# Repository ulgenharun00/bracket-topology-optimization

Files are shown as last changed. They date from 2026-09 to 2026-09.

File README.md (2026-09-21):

# Structural Optimization & Lightweighting of an Industrial Robot Arm Bracket




This repository contains the CAD models, FEA simulation results for a topology optimized robot arm bracket under a **500 N peak dynamic load**.

## 📌 Project Overview
* **Objective:** Reduce inertia and mass at the robot flange while strictly preserving structural rigidity and conventional machinability (DFM).
* **Baseline Material:** Structural Steel S235JR
* **Substituted Material:** EN AW-6061-T6 Aluminum Alloy

## 📊 Key Results & Comparison
| Metric / Parameter | Baseline Steel Bracket | Optimized Aluminum Bracket | Change |
| :--- | :---: | :---: | :---: |
| **Mass** | 742.16 g | **199.06 g** | **-73.18%** |
| **Peak von Mises Stress** | 20.67 MPa | 22.64 MPa | Well within yield limit |
| **Static Safety Factor** | 11.37 | **10.60** | Safe |
| **Max Total Deflection** | 0.027 mm | **0.071 mm** | Within L/1000 (0.080 mm) |
| **Fatigue Safety Factor**| 7.02 | **2.65** | Infinite Life (> 10^9 cycles) |

## 🛠️ Software & Standards Used
* **CAD:** SolidWorks (Part Modeling, Technical Drawings)
* **FEA:** ANSYS Mechanical (Adaptive Mesh Convergence, Fatigue Analysis, Topology Optimization)
* **Engineering Standards:** DIN EN 10056-1, ISO 898-1 (Class 8.8 Fasteners), DIN EN ISO 7090, Tabellenbuch Metall

## 📁 Repository Contents
* `/Report`: Complete 26 page engineering report.
* `/CAD`: SolidWorks (.SLDPRT) and neutral (.STEP) exchange models for both designs.
* `/Drawings`: Manufacturing drawings.
* `/Media` : High resolution stress plots and optimization density maps.

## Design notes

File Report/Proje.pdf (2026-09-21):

## Structural Optimization and Economic Feasibility of an Industrial Robot Arm Bracket

### 1. Design Load & Operating Scenario

The L-bracket serves as the structural interface between the robot flange and the end effector. To establish the design boundary conditions, a worst case scenario is assumed that 4g peak dynamic acceleration is induced as the on a robot arm handling a hypothetical 10 kg payload capacity:

F = m ⋅ (g + amax) = 10 kg × (9.81 + 40) m/s² ≈ 500 N

### 2. Bending Moment at the Root Section

The horizontal leg is evaluated as a cantilever beam with an effective overhang length of L = 80 mm. The peak bending moment acting on the fixed root section is:

Mb = F ⋅ L = 500 N ⋅ 80 mm = 40 000 N ⋅ mm

### 3. Allowable Stress & Safety Requirement

Baseline Design A utilizes standard structural steel S235JR (Re = 235 MPa). To ensure durability and prevent early plastic deformation under dynamic cyclic loading, an engineering safety factor of ν = 2.0 is defined:

σbzul =

σbF
v

=

235 MPa
2.0

= 117.5 MPa

### 4. Minimum Wall Thickness Calculation

Considering the bracket width as B = 80 mm, the required section modulus (Werf) to sustain the bending load is:

Werf =

Mb

σbzul

=

40 000 N ⋅ mm
117.5 N/mm² ≈ 340.4 mm³

Modeling the root section as a rectangular profile (W =

B⋅t

2

6

), the theoretical minimum wall thickness (terf) is derived as:

W =

B ⋅ t

2
6

⟹ terf = √
6 ⋅ Werf
B

= √
6 ⋅ 340.4 mm³
80 mm

≈ 5.05 mm

### 5. Standard Profile Selection

To maintain a safe structural margin, resist dynamic fatigue, and compensate for stress concentrations around the mounting holes, standard profile L 80 × 80 × 8 (DIN EN 10056-1)
[2] is selected. The nominal thickness of t = 8 mm safely exceeds the analytical minimum requirement of 5.05 mm.

Note: While σbF ≈ 1.2 ⋅ Re per Tabellenbuch Metall [1], using unmodified Re provides a conservative safety margin.

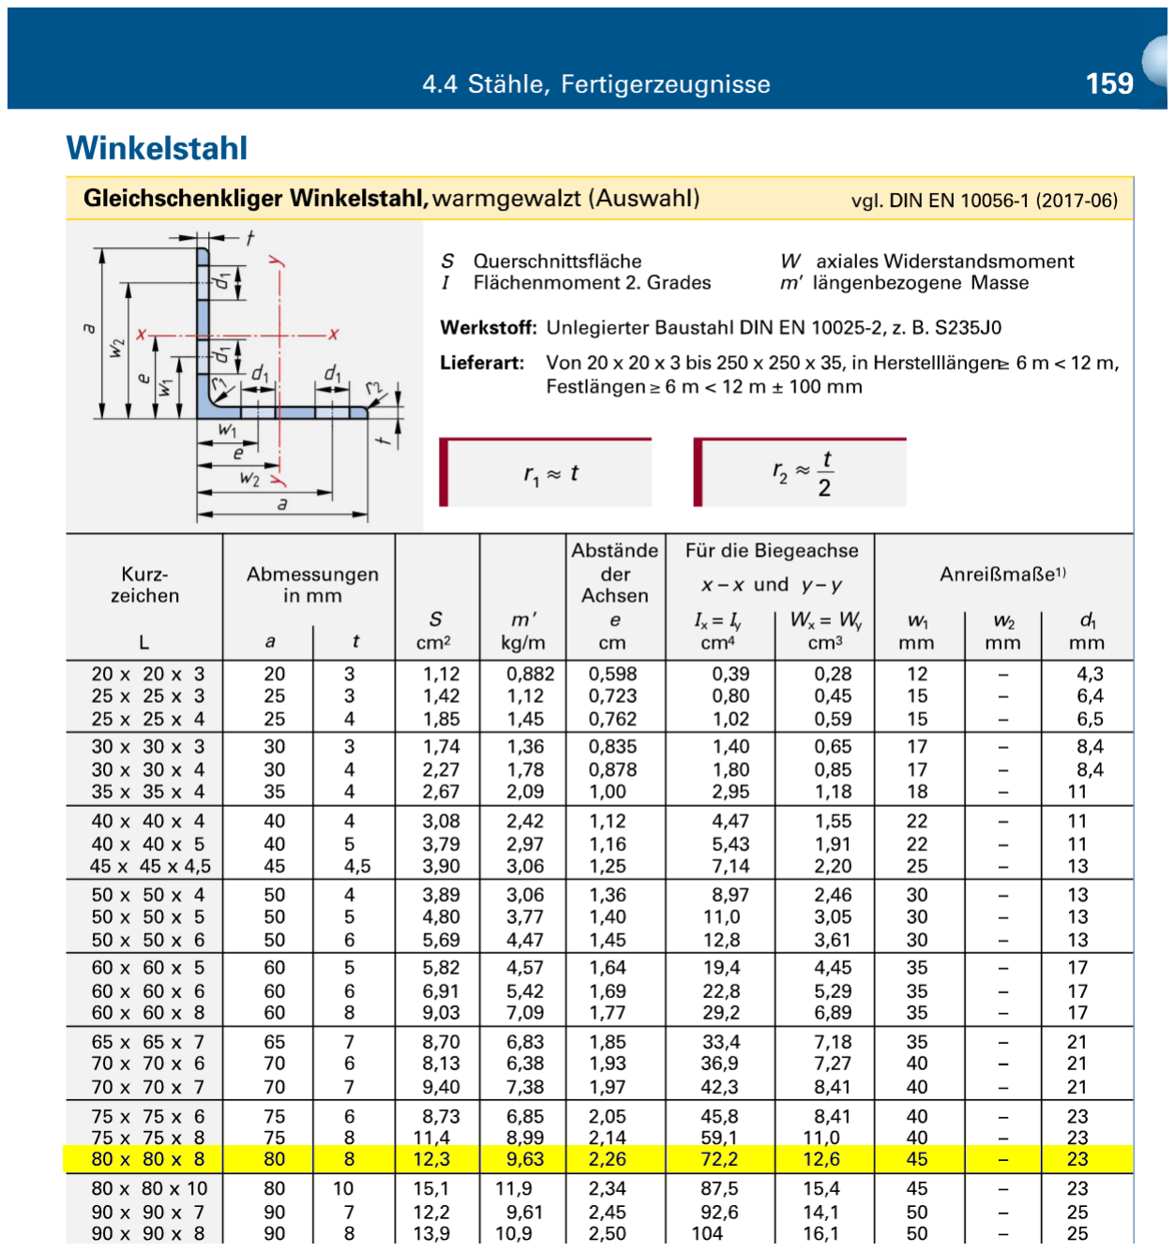
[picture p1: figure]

Figure 5.1: Geometric dimensions for equal leg angle profiles per DIN EN 10056-1 [2].

### 6. Fastener and Hole Selection

To secure the bracket assembly under static and dynamic loading, standard metric bolts and appropriate clearance dimensions must be established. The selection must comply with the geometric constraints of the chosen profile and prevent any local surface yield.

### 6.1. Fastener Strength Class

An M16 bolt is selected to carry the applied F = 500 N load and provide sufficient clamping force. To ensure high fatigue resistance and prevent plastic deformation under dynamic operating conditions, Property Class 8.8 per ISO 898-1 [3] is specified.

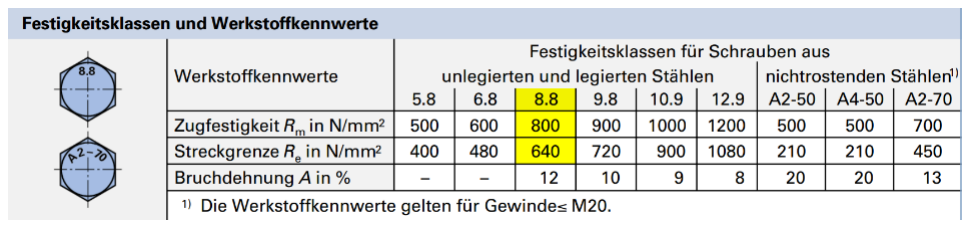
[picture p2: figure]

Figure 6.1: Mechanical properties of bolt strength classes per ISO 898-1 [3].

As detailed in Figure 6.1, a class 8.8 fastener provides a nominal tensile strength of Rm = 800 MPa and a yield strength of Re = 640 MPa, offering a massive safety margin for this application.

### 6.2. Clearance Hole and Profile Constraints

According to the geometric properties of the L 80 × 80 × 8 standard profile (Figure 5.1), the maximum allowable hole diameter for the flange is structurally limited to d1 = 23 mm.

To allow easy assembly while preventing loose play, the through hole is selected per DIN EN 20273 [4].

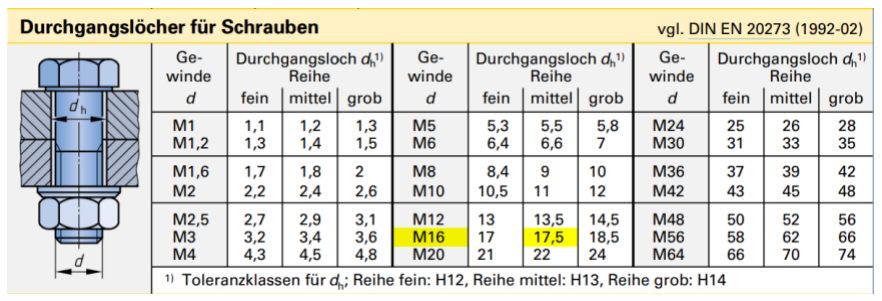
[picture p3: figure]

Figure 6.2: Clearance hole dimensions for metric fasteners per DIN EN 20273 [4].

As shown in Figure 6.2, the medium tolerance series specifies a nominal clearance hole of dℎ = 17.5 mm. This selection satisfies the profile's geometric constraint (17.5 mm ≤ 23.0 mm) while ensuring sufficient clamping surface.

### 6.3. Washer Selection

Since the bracket is made of aluminum (EN AW-6061-T6), high contact pressure can cause local surface indentation. A flat washer is added to distribute the clamping force and protect the softer material.

A standard chamfered flat washer per DIN EN ISO 7090 (Normal Series) [5] is selected.

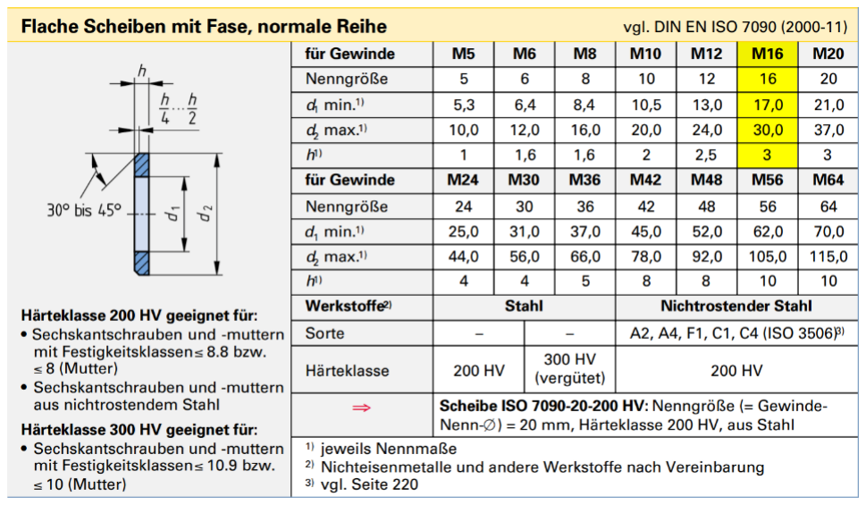
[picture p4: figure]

Figure 6.3: Standard dimensions for normal series flat washers per DIN EN ISO 7090 [5].

Based on Figure 6.3, the required washer for an M16 thread has an inner diameter of d1 = 17.0 mm, an outer diameter of d2 = 30.0 mm, and a thickness of ℎ = 3.0 mm. To accommodate this 30 mm washer and standard socket tool clearances, a planar mounting boss with a diameter of Dboss = 34 mm is implemented in the CAD geometry.

### 7. Baseline CAD Modeling and Technical Drawing

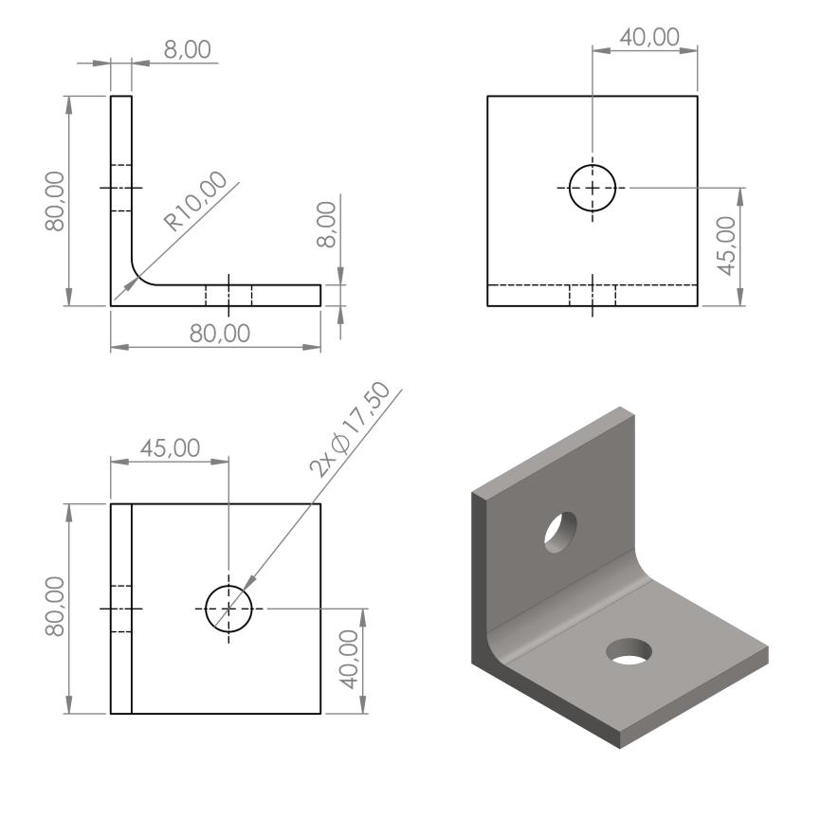
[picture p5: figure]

Figure 7.1: Technical drawing and nominal dimensions of the baseline steel L bracket (S235JR).

The baseline CAD model of the L bracket has dimensions of 80 × 80 × 80 mm, a uniform thickness of t = 8.0 mm, and an inner fillet radius of R = 10.0 mm. To accommodate the M16 bolts and washers selected in Section 6, two clearance holes with a diameter of ∅17.5 mm are positioned at the center of each face.

The complete technical drawing is provided in Appendix A. This geometry serves as the reference model for the structural analysis.

### 8. Structural Analysis of the Baseline Bracket

### 8.1. Material Properties

The baseline bracket is manufactured from structural steel S235JR (material number 1.0037). In ANSYS Mechanical, the material is modeled as linear elastic and isotropic. The yield strength of 235 MPa is defined as the critical threshold for the structural safety factor evaluation based on the von Mises equivalent stress criterion.

Table 8.1: Mechanical properties of S235JR steel defined in ANSYS Engineering Data.

Property | Symbol | Value | Unit
Density | ρ | 7850 | kg/m³
Young's Modulus | E | 2.1 × 10⁵ | MPa
Poisson's Ratio | ν | 0.30 | —
Bulk Modulus | K | 1.75 × 10¹¹ | Pa
Shear Modulus | G | 8.077 × 10¹⁰ | Pa
Tensile Yield Strength | ReH | 235 | MPa

### 8.2 Fatigue Properties (Synthetic S-N Curve)

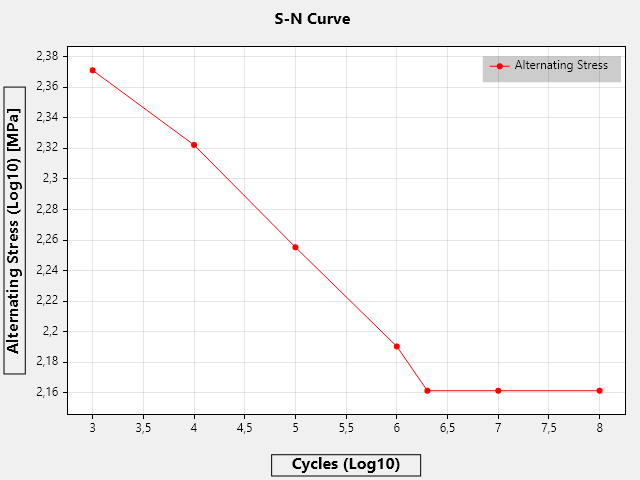
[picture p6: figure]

Figure 8.2: Synthetic S-N curve for S235JR steel.

Due to the absence of experimental fatigue test data, a synthetic S-N curve for S235JR was defined according to standard analytical guidelines for fully reversed loading (R = −1). The endurance limit was set to 145 MPa (≈ 0.4 ⋅ Rm) with an elastic threshold at the yield strength (235 MPa).

### 8.3. Boundary Conditions and Applied Load

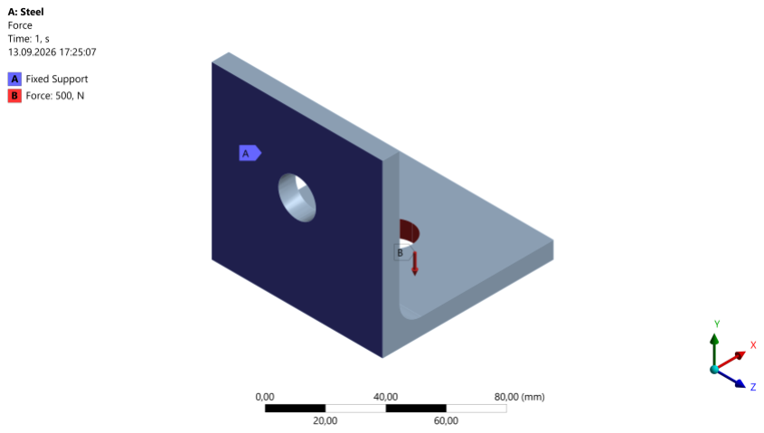
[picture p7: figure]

Figure 8.3: Boundary conditions and applied load on the baseline bracket model.

Boundary conditions were applied in ANSYS Mechanical as shown in Figure 8.2. The rear face of the vertical section was fully constrained using a fixed support. A static downward load of 500 N was applied to the inner surface of the hole on the horizontal section in the negative Y direction

Table 8.3: Mesh convergence results for the baseline bracket model.

Solution

Number | Nodes | Elements | Max. Equivalent Stress [MPa] | Relative Change [%]
1 | 1,827 | 825 | 14.59 | —
2 | 7,254 | 4,091 | 18.93 | 25.89
3 | 25,924 | 16,681 | 20.44 | 7.67
4 | 106,531 | 73,290 | 20.67 | 1.13

### 8.4. Mesh Convergence Study

A mesh convergence study was conducted using adaptive refinement on the maximum equivalent stress to ensure mesh independent results. The allowable change criterion was set to 2.5%. Convergence was achieved at the fourth iteration with 73,290 elements, where the relative change dropped to 1.13%, yielding a maximum equivalent stress of 20.67 MPa.

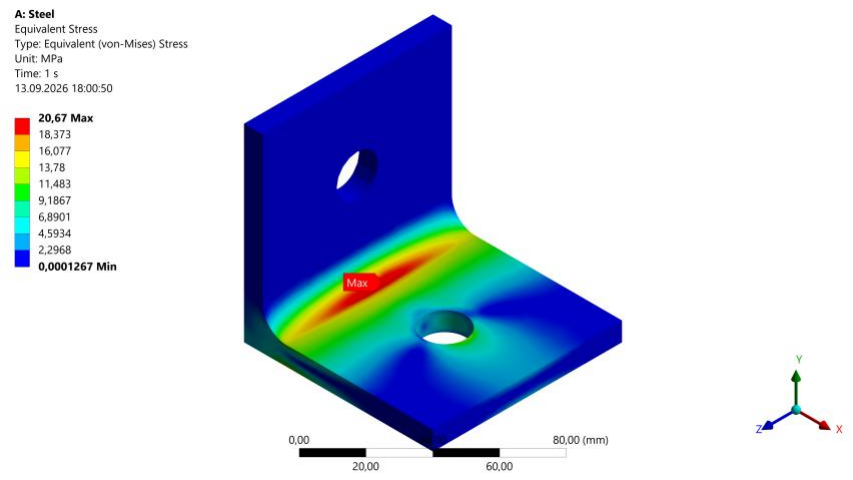
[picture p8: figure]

Figure 8.5: Equivalent (von Mises) stress distribution on the baseline bracket model.

### 8.5. Static Stress Results

The FEA yields a converged maximum equivalent stress of 20.67 MPa under the 500 N peak load, as shown in Figure 8.3. The peak stress is concentrated along the inner radius between the vertical and horizontal sections due to bending. Comparing this result with the yield strength of S235JR steel (235 MPa) confirms that the structure remains well within the elastic region with a static safety factor above 11.

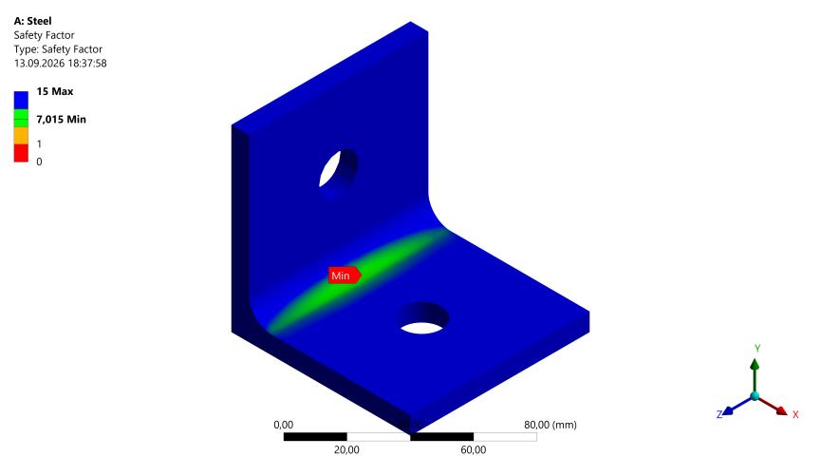
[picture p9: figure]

Figure 8.6: Fatigue safety factor distribution of the bracket model.

### 8.6. Fatigue Analysis Results

A fatigue assessment was conducted under fully reversed cyclic loading using the stress life method as shown in Figure 8.4. The minimum fatigue safety factor was determined as 7.015 at the inner radius between the vertical and horizontal sections. As a consequence of this low stress amplitude, the entire structure achieves infinite fatigue life exceeding 10⁸
cycles.

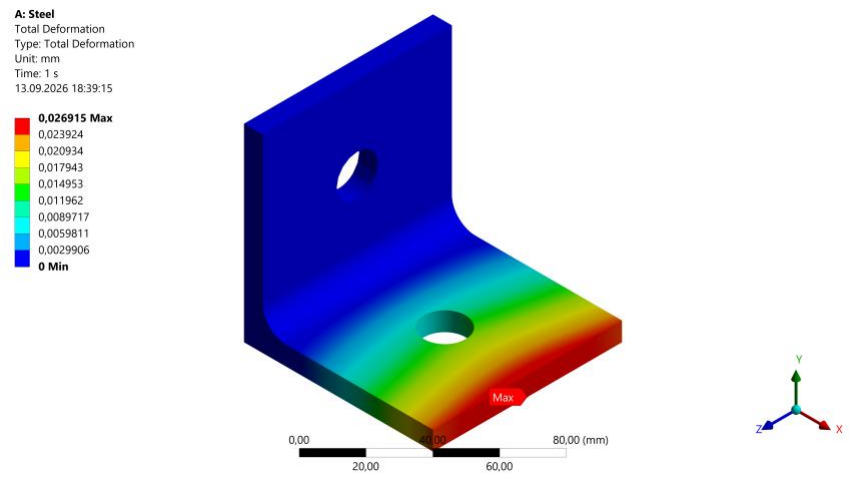
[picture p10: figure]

Figure 8.7: Total deformation distribution of the baseline bracket model.

### 8.7. Deformation Results

The total displacement distribution resulting from the 500 N peak load is presented in Figure
8.5. The maximum deflection is 0.027 mm, located at the free outer edge of the horizontal flange. Considering the 80 mm total cantilever length from the fixed support, this deformation corresponds to approximately L/3000, well within the standard industrial machine stiffness limit of L/1000 (0.080 mm). This confirms high structural rigidity and ensures that elastic deflections will not impair functional clearances.

### 8.8. Structural Evaluation and Lightweighting Strategy

The baseline structural steel (S235JR) bracket is substantially over dimensioned under the operational 500 N peak load, exhibiting a static safety factor exceeding 11, a minimum fatigue safety factor of 7.015, and a peak deflection of only 0.027 mm. Given these excessive safety margins, the bracket does not require the mechanical strength offered by structural steel. Consequently, the material will be substituted with a lower strength alternative, EN AW-6061-T6 aluminum alloy, to evaluate structural adequacy in the subsequent analyses.

### 9. Structural Analysis of the EN AW-6061-T6 Bracket

### 9.1. Material Properties

The bracket material is substituted with precipitation-hardened aluminum alloy EN AW-6061-T6 (material number 3.3211 / AlMg1SiCu). In ANSYS Mechanical, the material is modeled as linear elastic and isotropic. A yield strength of 275 MPa is defined as the critical threshold for the structural safety factor evaluation based on the von Mises equivalent stress criterion.

Table 9.1: Mechanical properties of EN AW-6061-T6 aluminum alloy defined in ANSYS Engineering Data.

Property | Symbol | Value | Unit
Density | ρ | 2700 | kg/m³
Young's Modulus | E | 6.9 × 10⁴ | MPa
Poisson's Ratio | ν | 0.33 | —
Bulk Modulus | K | 6.765 × 10¹⁰ | Pa
Shear Modulus | G | 2.594 × 10¹⁰ | Pa
Tensile Yield Strength | Rp0.2 | 275 | MPa

### 9.2. Fatigue Properties (Synthetic S-N Curve)

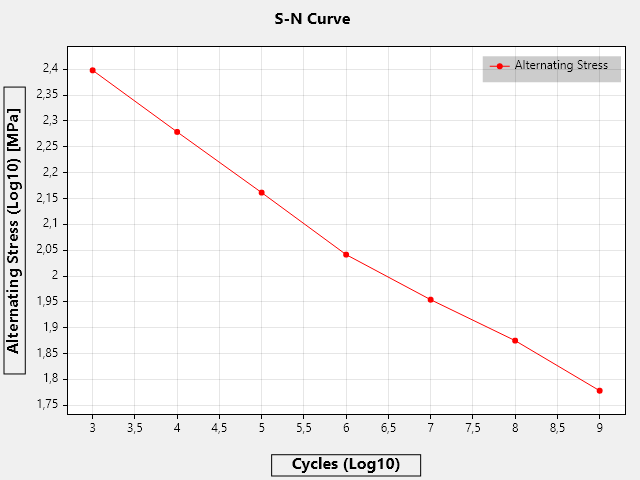
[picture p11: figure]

Figure 9.2: S-N curve for EN AW-6061-T6 aluminum alloy.

The fatigue behavior of EN AW-6061-T6 is defined using the S-N curve for fully reversed loading (R = −1). In accordance with typical non ferrous material characteristics, the fatigue strength decreases continuously across the cycle range without exhibiting a distinct endurance limit.

### 9.3. Boundary Conditions and Applied Load

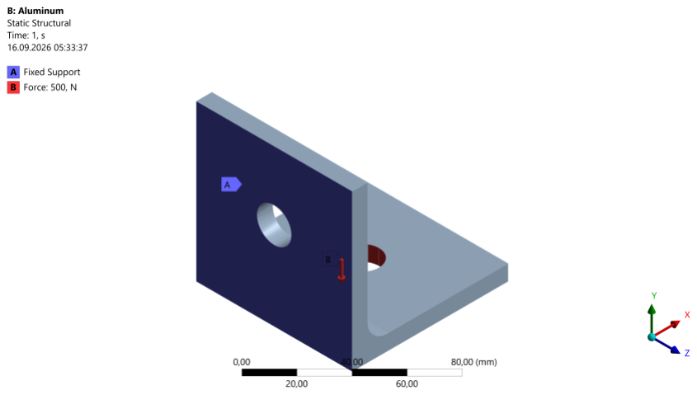
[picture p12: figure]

Figure 9.3: Boundary conditions and applied load for the EN AW-6061-T6 bracket model.

The boundary conditions and load application remained identical to the baseline configuration, as illustrated in Figure 9.3. The rear surface of the vertical section was fully constrained using a fixed support, and a static downward load of 500 N was applied to the inner cylindrical surface of the horizontal hole in the negative Y direction.

Table 9.4: Mesh convergence results for the EN AW-6061-T6 bracket model.

Solution

Number | Nodes | Elements | Max. Equivalent Stress [MPa] | Relative Change [%]
1 | 1,827 | 825 | 14.52 | —
2 | 7,254 | 4,091 | 18.89 | 26.17
3 | 25,783 | 16,577 | 20.40 | 7.67
4 | 106,452 | 73,226 | 20.65 | 1.23

### 9.4. Mesh Convergence Study

A mesh convergence study was conducted using adaptive refinement on the maximum equivalent stress to ensure mesh independent results for the EN AW-6061-T6 aluminum bracket model. The allowable change criterion was set to 2.5%. Convergence was successfully achieved at the fourth iteration with 73,226 elements (106,452 nodes), where the relative change dropped to 1.23%, well below the convergence threshold. The converged maximum equivalent stress was evaluated as 20.65 MPa.

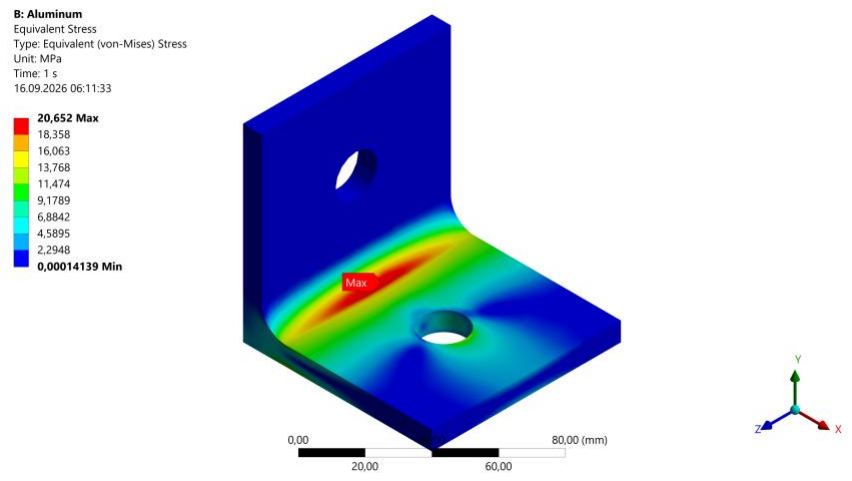
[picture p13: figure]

Figure 9.5: Equivalent (von Mises) stress distribution of the EN AW-6061-T6 aluminum bracket model.

### 9.5. Static Stress Results

The FEA yields a converged maximum equivalent stress of 20.65 MPa under the 500 N peak load, as shown in Figure 9.3. Similar to the baseline steel model, the peak stress is concentrated along the inner fillet radius between the vertical and horizontal sections due to the primary bending moment. Comparing this value with the yield strength of EN AW-6061-T6 aluminum alloy (Rp0.2 = 275 MPa) confirms that the structure operates well within the linear elastic regime, providing a high static safety factor of approximately 13.3 (SF = 275/20.65).

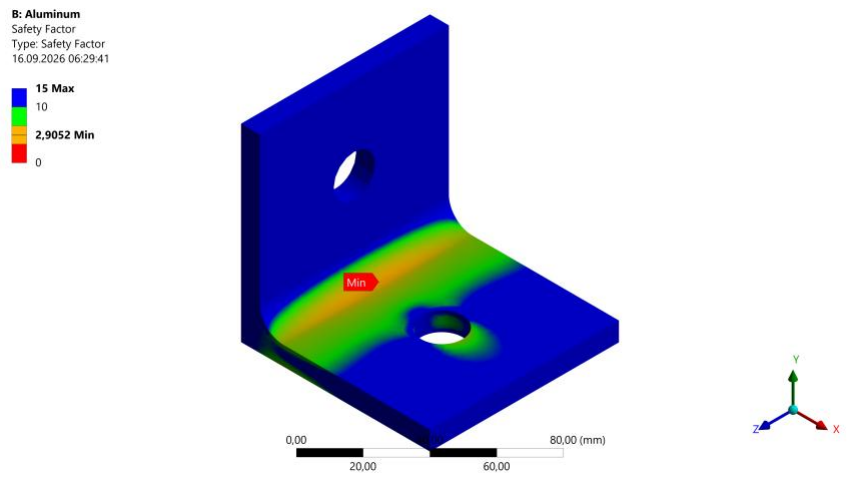
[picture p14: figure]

Figure 9.6: Fatigue safety factor distribution of the EN AW-6061-T6 aluminum bracket model.

### 9.6. Fatigue Analysis Results

A fatigue assessment was conducted under fully reversed cyclic loading using the stress life (S-N) approach, as illustrated in Figure 9.4. The minimum fatigue safety factor was determined as 2.91, located along the inner fillet radius between the vertical and horizontal sections where cyclic bending stresses peak.

Because the alternating stress amplitude remains well below the fatigue endurance limit for the specified design criteria, the entire structure achieves infinite fatigue life, reaching the maximum design life limit of 10⁹
cycles. Although this safety factor is lower than the baseline steel model (7.02) due to the inherently lower fatigue strength of aluminum alloys, a safety factor of 2.91 remains well above standard industrial design margins, confirming high structural integrity against cyclic failure under nominal 500 N dynamic loading.

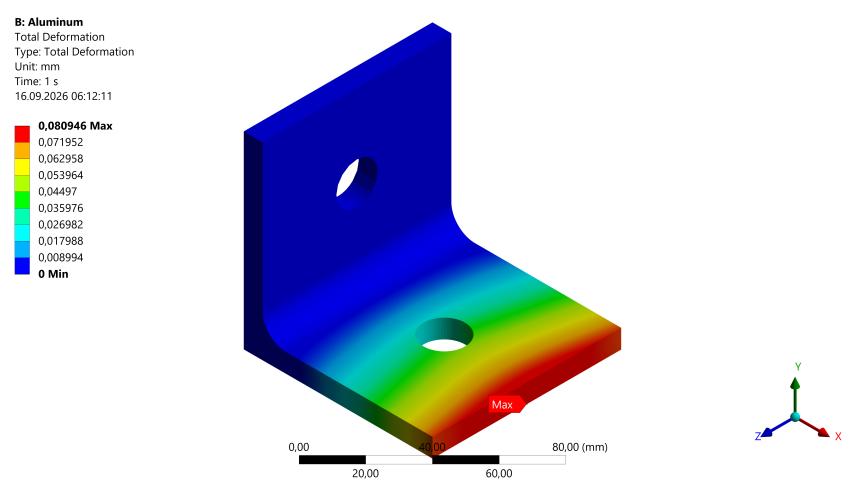
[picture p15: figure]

Figure 9.7: Total deformation distribution of the EN AW-6061-T6 aluminum bracket model.

### 9.7. Deformation Results

The total displacement distribution resulting from the 500 N peak load is presented in Figure
9.7. The maximum deflection is 0.081 mm, located at the free outer edge of the horizontal flange. Because the elastic modulus of aluminum (E = 69 GPa) is roughly one third that of structural steel (E = 210 GPa), the maximum displacement increases by approximately a factor of 3 compared to the steel baseline (0.027 mm).

Considering the 80 mm cantilever length from the fixed support, this deflection closely aligns with the standard industrial stiffness limit of L/1000 (0.080 mm). This verifies that the EN AW-6061-T6 bracket maintains sufficient structural rigidity and functional clearances under peak service loading.

### 9.8. Structural Evaluation and Lightweighting Strategy

The EN AW-6061-T6 aluminum bracket remains substantially understressed under the operational 500 N peak load, exhibiting a static safety factor of 13.3, a minimum fatigue safety factor of 2.91, and a maximum deflection of 0.081 mm. Although the direct material substitution successfully reduced mass while satisfying the L/1000 stiffness criterion, broad areas of the bracket still experience negligible stress levels. Given these remaining design margins, topology optimization will be conducted on the aluminum model to guide geometric lightweighting and evaluate a pocketed design variant in the subsequent analyses.

### 10. Topology Optimization

### 10.1. Optimization Setup and Boundary Conditions

To identify inefficient material volumes and guide structural lightweighting, density-based topology optimization was configured on the EN AW-6061-T6 aluminum bracket. The optimization setup and boundary constraints are shown in Figure 10.1.

The bracket body was designated as the active design domain (blue), allowing the solver to redistribute material density based on strain energy distribution. To preserve functional interfaces and structural connectivity, an exclusion region (red) was defined covering the rear fixed mounting face and the internal cylindrical surfaces of both fastener holes. The optimization objective was set to minimize compliance (maximize global stiffness) subject to a response constraint requiring a 50% mass retention of the design space.

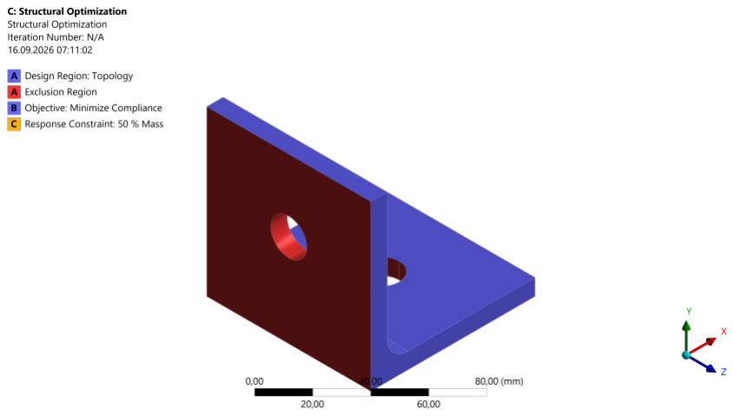
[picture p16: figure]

Figure 10.1: Boundary condition setup for topology optimization showing design (blue) and exclusion (red) regions.

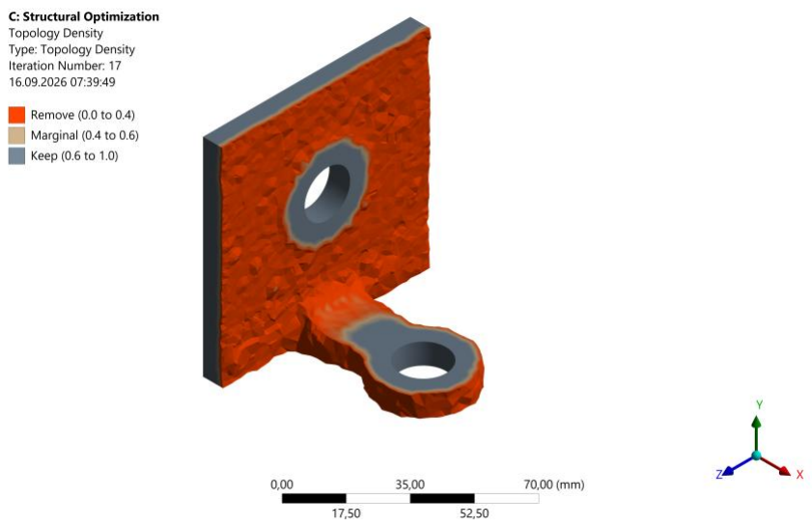
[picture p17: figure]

Figure 10.2: Material density distribution obtained from topology optimization.

### 10.2. Topology Optimization Results

The resulting material density distribution after 17 iterations is presented in Figure 10.2. The optimization algorithm identified a clear, direct load transfer path spanning from the horizontal fastener hole through the central fillet transition to the rear mounting face.

The outer lateral corners of the horizontal flange exhibit near zero strain energy and are identified as redundant material. While the raw organic geometry produced by the solver is unfeasible for conventional machining, it establishes the physical basis for the subsequent CAD redesign. In the redesigned model, the unneeded outer corners are trimmed and contoured around the fastener hole to mirror this primary load path while ensuring conventional manufacturability.

### 10.3. CAD Redesign Based on Topology Optimization

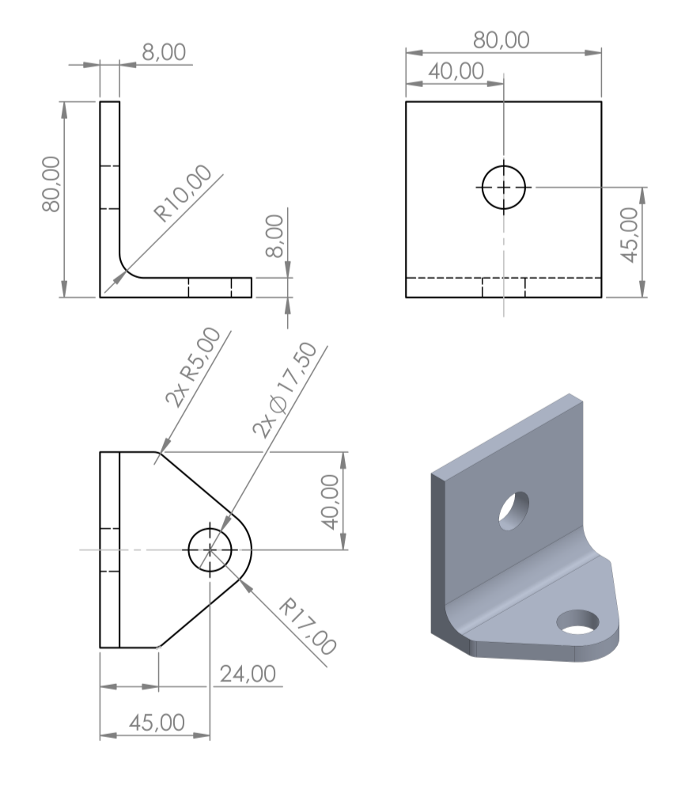
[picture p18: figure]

Figure 10.3: Technical manufacturing drawing and 3D CAD model of the optimized lightweight bracket

Based on the topology optimization results, the bracket was redesigned in SolidWorks to remove inactive material. The non load bearing outer corners of the horizontal flange were trimmed, and transition fillets were added to ensure conventional manufacturability while preventing stress concentrations.

### 10.4 Structural Analysis of the Optimized Bracket

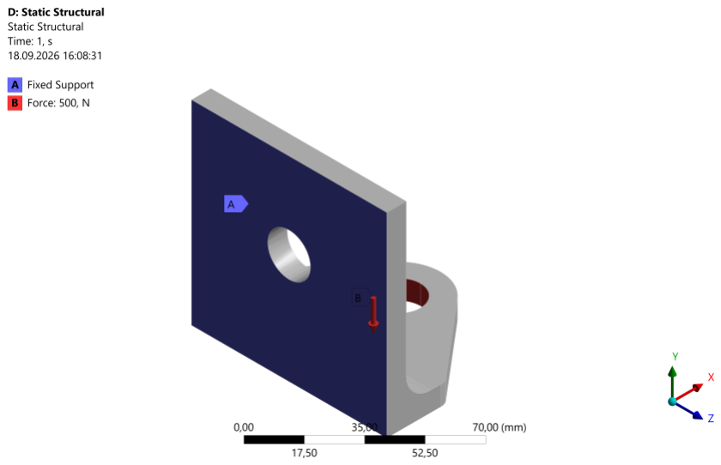
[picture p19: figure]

Figure 10.4: Boundary conditions and applied load on the optimized bracket model.

Boundary conditions were applied in ANSYS Mechanical as shown in Figure 10.4. The rear face of the vertical section was fully constrained using a fixed support. A static downward load of 500 N was applied to the inner surface of the hole on the horizontal section in the negative Y direction.

Table 10.1: Mesh convergence results for the optimized bracket model.

Solution

Number | Nodes | Elements | Max. Equivalent Stress [MPa] | Relative Change [%]
1 | 1,866 | 852 | 18,39 | —
2 | 8,056 | 4,619 | 20,31 | 9,94
3 | 30,110 | 19,646 | 22,39 | 9,71
4 | 104,991 | 72,500 | 22,64 | 1.13

### 10.5. Mesh Convergence Study

A mesh convergence study was conducted using adaptive refinement on the maximum equivalent stress to ensure mesh-independent results. The allowable change criterion was set to 2.5%. Convergence was achieved at the fourth iteration with 72,500 elements (104,991 nodes), where the relative change dropped to 1.13%, yielding a maximum equivalent stress of 22.64 MPa.

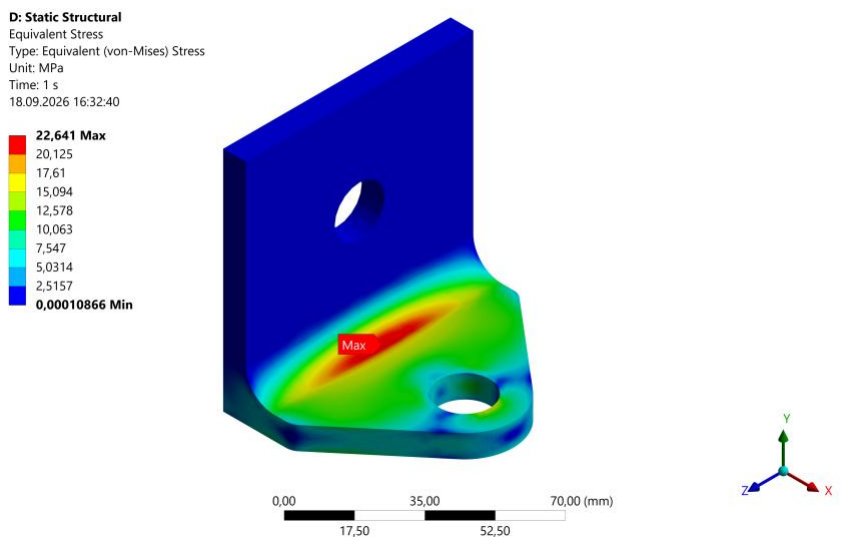
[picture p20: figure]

Figure 10.5: Equivalent (von Mises) stress distribution on the optimized bracket model.

### 10.6. Static Stress Results

The FEA yields a converged maximum equivalent stress of 22.64 MPa under the 500 N peak load, as shown in Figure 10.5. The peak stress is concentrated along the inner radius between the vertical and horizontal sections due to bending. Comparing this result with the yield strength of EN AW-6061-T6 aluminum (240 MPa) confirms that the structure remains well within the elastic region with a static safety factor of approximately 10.6.

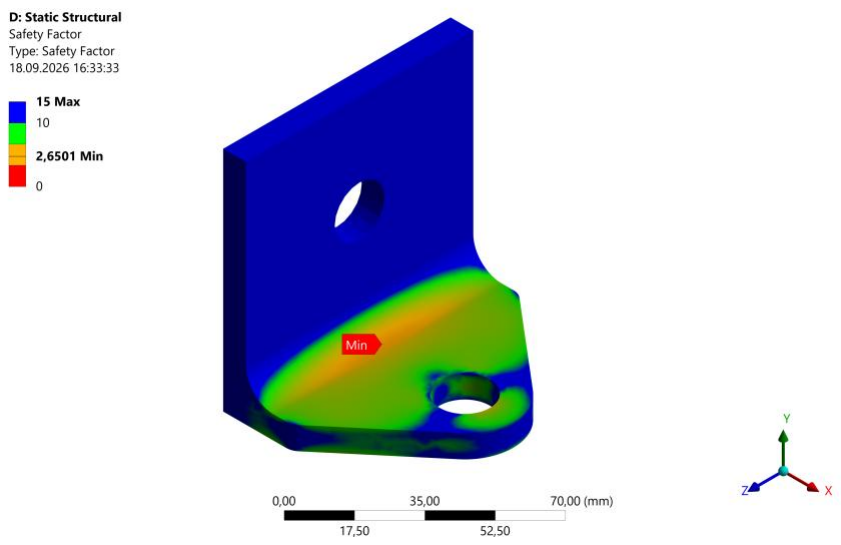
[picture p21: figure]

Figure 10.6: Fatigue safety factor distribution of the optimized bracket model

### 10.7. Fatigue Analysis Results

A fatigue assessment was conducted under fully reversed cyclic loading using the stress-life method, as shown in Figure 10.6. The minimum fatigue safety factor was determined to be 2.65 at the inner radius between the vertical and horizontal sections. As a consequence of this low stress amplitude, the entire structure achieves infinite fatigue life exceeding 10⁹
cycles.

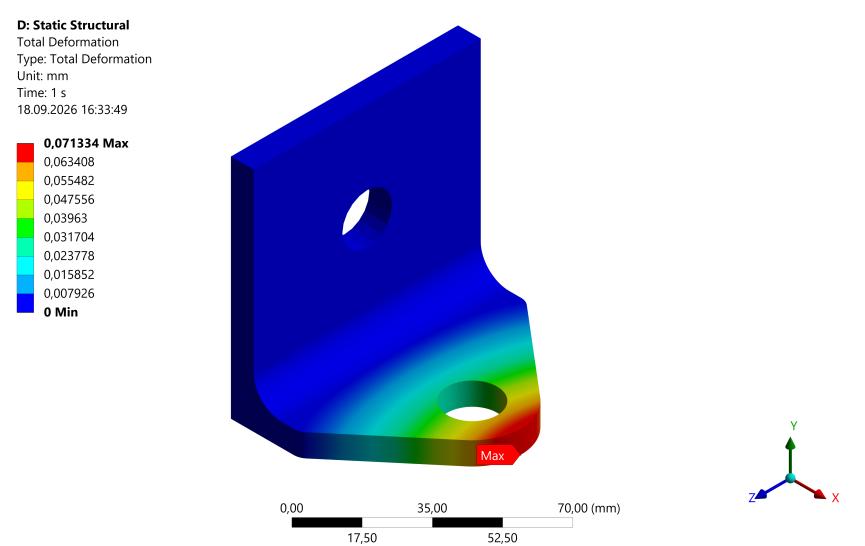
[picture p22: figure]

Figure 10.7: Total deformation distribution of the optimized bracket model.

### 10.8. Deformation Results

The total displacement distribution resulting from the 500 N peak load is presented in Figure
10.7. The maximum deflection is 0.071 mm, located at the free outer edge of the horizontal flange. Considering the 80 mm total cantilever length from the fixed support, this deformation corresponds to approximately L/1120, remaining within the standard industrial machine stiffness limit of L/1000 (0.080 mm). This confirms adequate structural rigidity and ensures that elastic deflections will not impair functional clearances.

Table 10.2: Comprehensive structural and mass comparison across design iterations.

Metric / Parameter

Baseline Steel
Bracket

(S235JR)

Aluminum Bracket

(EN AW-6061-T6)

Optimized Aluminum
Bracket

(EN AW-6061-T6)

Material Density
[kg/m3
]
7850 | 2700 | 2700
Part Mass [g] | 742,16 | 256,90 | 199,06

Mass Reduction
[%] | 0% | 65,38% | 73,18%

Max. Equivalent
Stress [MPa]
20,67 | 20,65 | 22,64

Yield Strength
[MPa]
235 | 240 | 240

Static Safety
Factor | 11,37 | 11,62 | 10,60

Max. Total
Deformation [mm]
0,027 | 0,081 | 0,071

Min. Fatigue
Safety Factor | 7,02 | 2,91 | 2,65

### 10.9. Comparative Discussion and Technoeconomic Evaluation

The transition from structural steel to the optimized aluminum bracket achieves an overall mass reduction of 73,18%, decreasing the weight from 742,16 g to 199,06 g. Material substitution yields an initial 65,38% saving, while trimming the inactive corner regions provides an additional 22,51% reduction. Under the 500 N operational load, structural integrity is fully maintained: the peak von Mises stress of 22,64 MPa remains well below the 240 MPa yield strength of EN AW-6061-T6 (safety factor: 10.60), and the maximum deflection of 0,071 mm stays strictly within the 0,080 mm (L/1000) stiffness limit.

Economically, converting the topology optimization distribution into a standard trimmed geometry ensures low cost fabrication via conventional machining, eliminating the need for expensive additive manufacturing. Although aluminum has a higher base price per kilogram than structural steel, the substantial weight reduction offsets raw material costs while minimizing structural inertia, achieving a practical and cost effective lightweight design.

### 11. Conclusion

In this study, a structural steel (S235JR) L bracket was redesigned and lightened through material substitution and topology driven geometric optimization under an operational peak load of 500 N. Transitioning to EN AW-6061-T6 aluminum combined with trimming inactive lateral corner material achieved an overall mass reduction of 73.18% (from 742.16 g to 199.06 g). Finite element validation with adaptive mesh convergence confirmed that structural integrity and functional requirements are fully satisfied: the peak von Mises stress of 22.64 MPa yields a static safety factor of 10,60, the fatigue safety factor of 2,65 ensures infinite life exceeding 10⁹
cycles, and the maximum deflection of 0,071 mm remains strictly within the standard L/1000 (0.080 mm) machine stiffness limit. By replacing organic topology contours with clean planar cuts, the final geometry guarantees low cost manufacturability via standard 3 axis CNC machining, achieving an optimal balance between structural rigidity, weight efficiency, and production economics.

[1] R. Gomeringer, R. Kilgus, V. Menges, S. Oesterle, et al., Tabellenbuch Metall mit Formelsammlung, 48th ed., Haan-Gruiten: Verlag Europa-Lehrmittel, 2022.
[2] DIN EN 10056-1:2017-06, Structural steel equal and unequal leg angles - Part 1: Dimensions, Berlin: DIN Media, 2017.
[3] ISO 898-1:2013-01, Mechanical properties of fasteners made of carbon steel and alloy steel - Part 1: Bolts, screws and studs with specified property classes, Geneva: International Organization for Standardization, 2013.
[4] DIN EN 20273:1992-02 (ISO 273:1979), Fasteners - Clearance holes for bolts and screws, Berlin: DIN Media, 1992.
[5] DIN EN ISO 7090:2000-11, Plain washers, chamfered - Normal series - Product grade A, Berlin: DIN Media, 2000.

Appendix A: Technical Drawing of the Baseline L Bracket

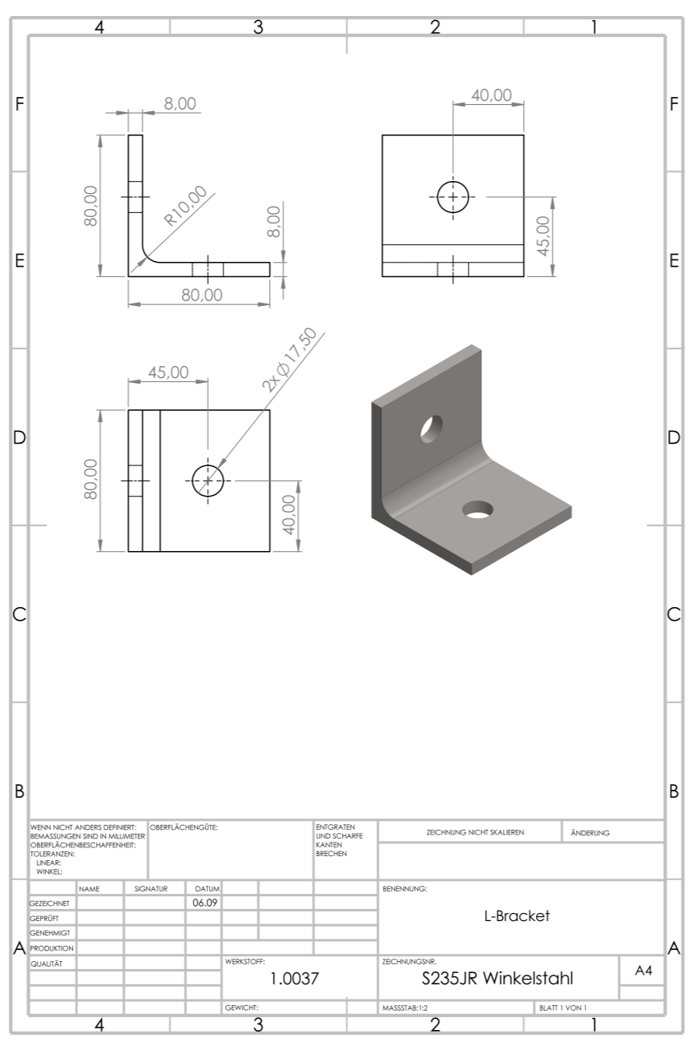
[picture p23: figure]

Appendix B: Technical Drawing of the Optimized Bracket

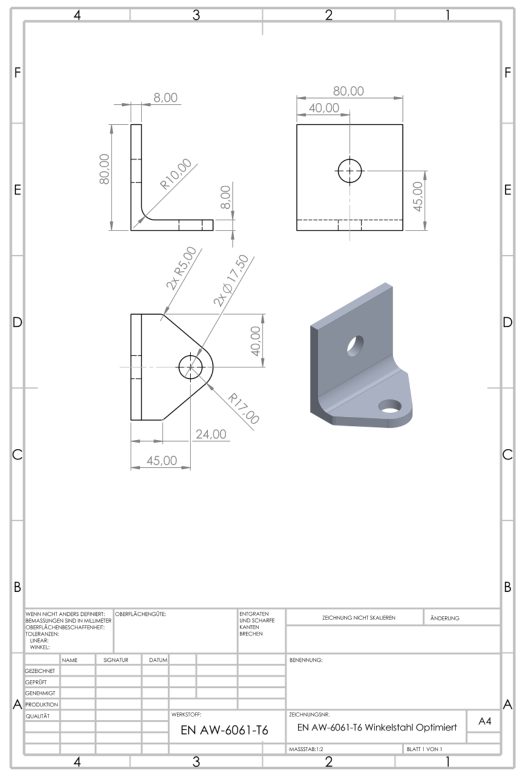
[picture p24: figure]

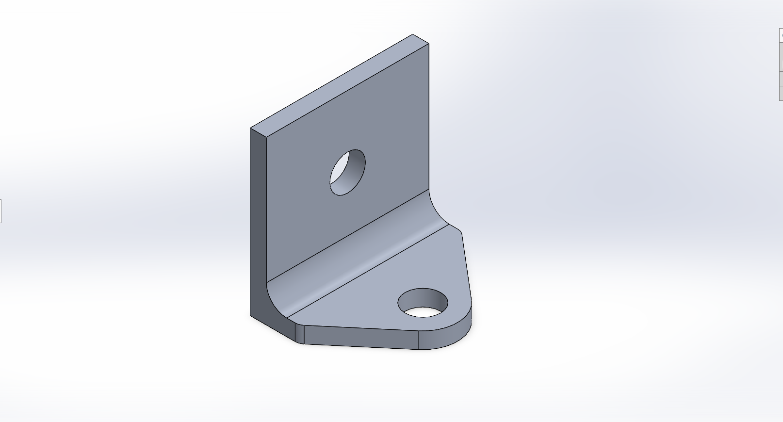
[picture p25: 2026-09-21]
Media/Picture3.png

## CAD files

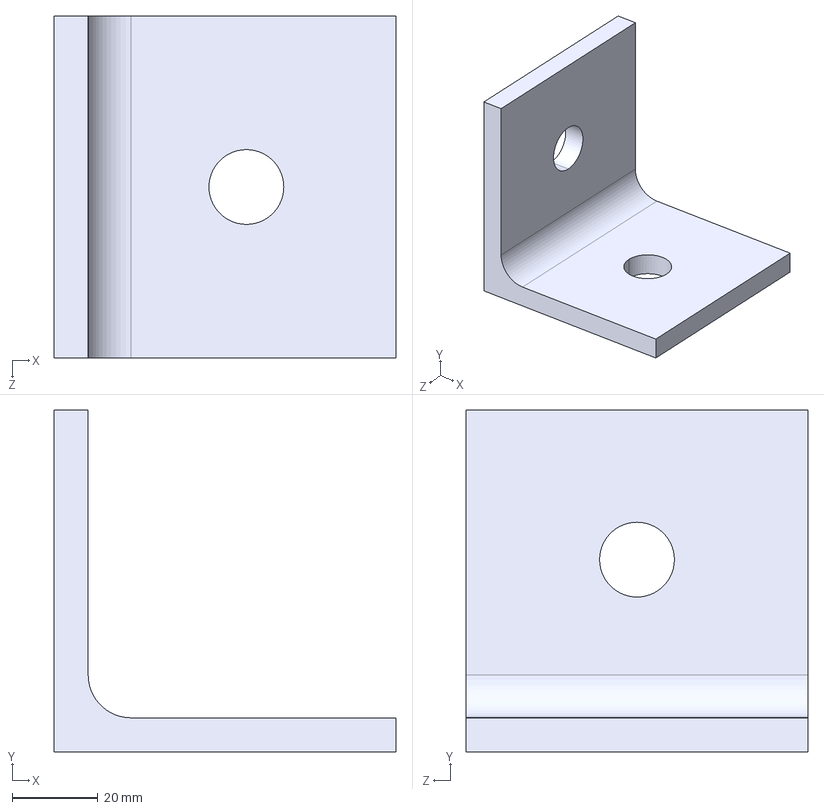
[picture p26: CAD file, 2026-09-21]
CAD/EN AW-6061-T6 Winkelstahl.STEP
80.0 x 80.0 x 80.0 mm

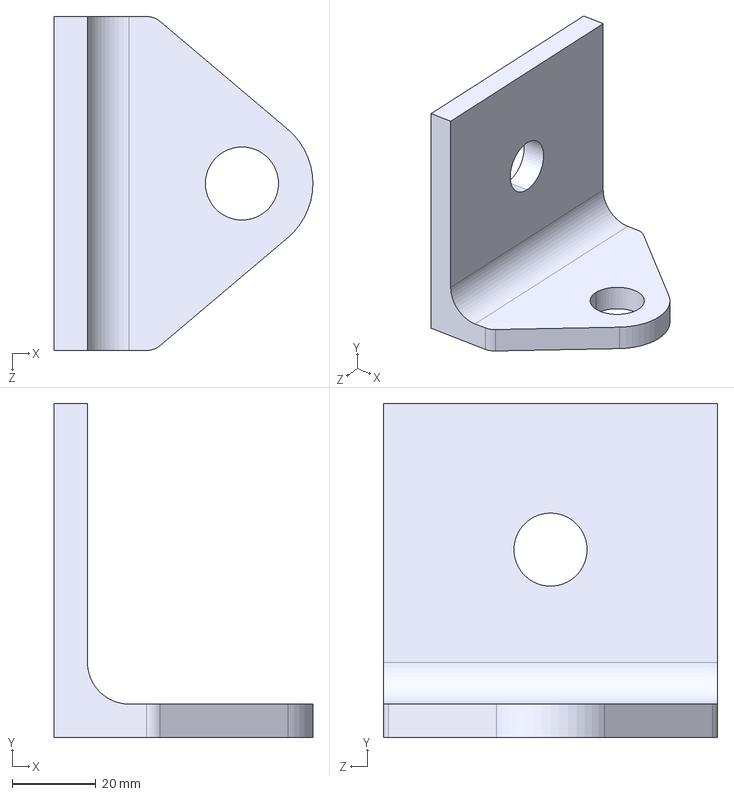
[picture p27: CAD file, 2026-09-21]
CAD/EN AW-6061-T6 Winkelstahl Optimiert.STEP
62.0 x 80.0 x 80.0 mm

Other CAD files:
CAD/S235JR Winkelstahl.STEP
CAD/EN AW-6061-T6 Winkelstahl Optimiert.SLDPRT
CAD/EN AW-6061-T6 Winkelstahl.SLDPRT
CAD/S235JR Winkelstahl.SLDPRT

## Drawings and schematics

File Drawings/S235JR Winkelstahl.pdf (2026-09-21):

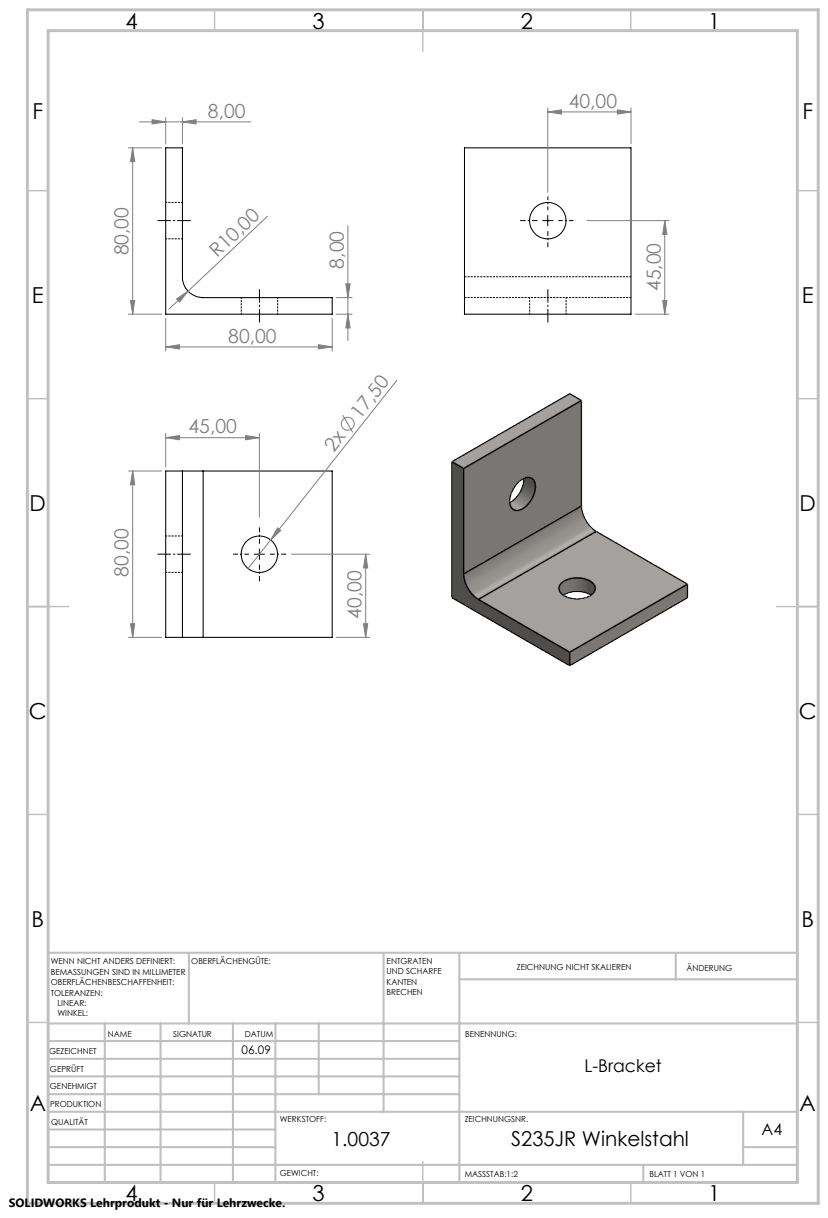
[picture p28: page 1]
MASSSTAB:1:2; BLATT 1 VON 1; ZEICHNUNG NICHT SKALIEREN; ÄNDERUNG; UND SCHARFE; WENN NICHT ANDERS DEFINIERT:; OBERFLÄCHENGÜTE:

BEMASSUNGEN SIND IN MILLIMETER
OBERFLÄCHENBESCHAFFENHEIT:
TOLERANZEN:
LINEAR:
WINKEL:

NAME | SIGNATUR | DATUM | | | | BENENNUNG: L-Bracket

GEZEICHNET | | | 06.09

GEPRÜFT
GENEHMIGT
PRODUKTION
QUALITÄT | | | | WERKSTOFF: 1.0037 | ZEICHNUNGSNR. S235JR Winkelstahl | A4

SOLIDWORKS Lehrprodukt - Nur für Lehrzwecke.

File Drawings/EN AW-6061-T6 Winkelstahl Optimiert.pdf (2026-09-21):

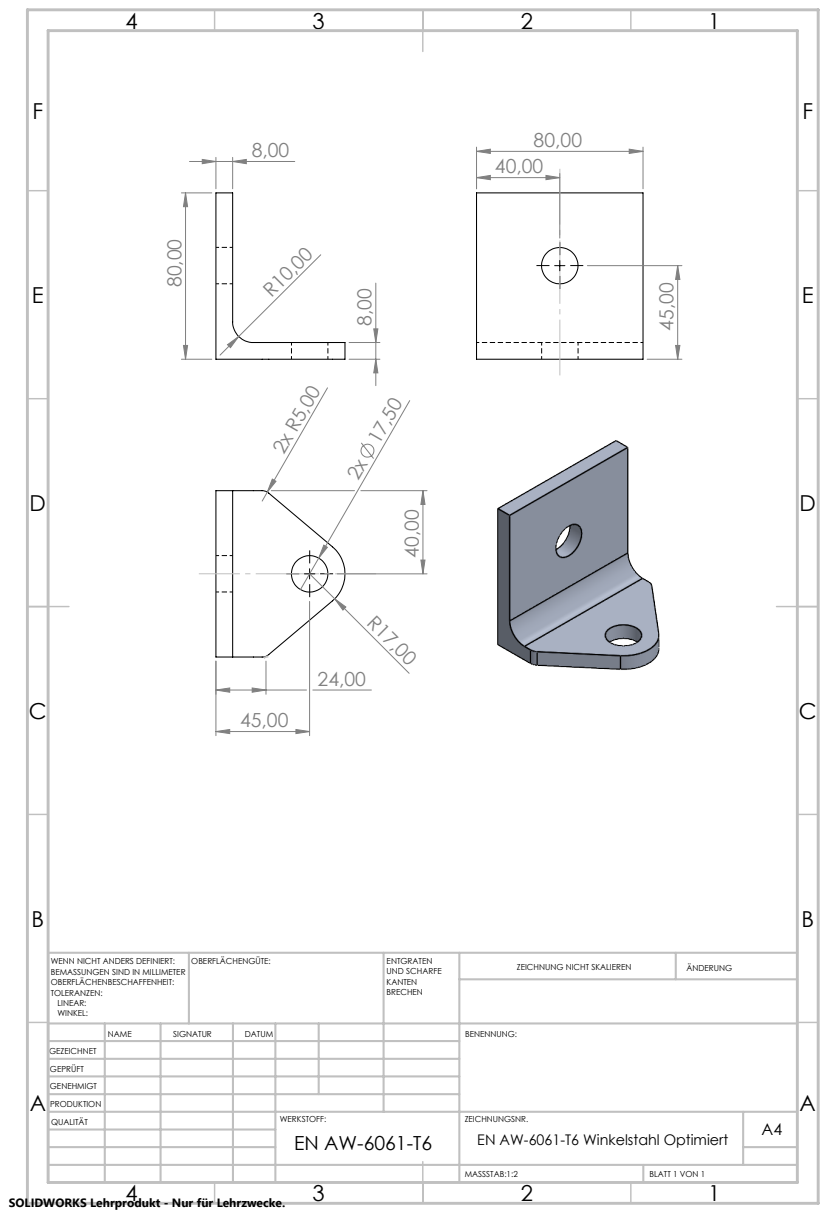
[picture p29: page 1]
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

BEMASSUNGEN SIND IN MILLIMETER
OBERFLÄCHENBESCHAFFENHEIT:
TOLERANZEN:
LINEAR:
WINKEL:

NAME | SIGNATUR | DATUM | | | | BENENNUNG:

GEZEICHNET
GEPRÜFT
GENEHMIGT
PRODUKTION
QUALITÄT | | | | WERKSTOFF: EN AW-6061-T6 | ZEICHNUNGSNR. EN AW-6061-T6 Winkelstahl Optimiert | A4

SOLIDWORKS Lehrprodukt - Nur für Lehrzwecke.
